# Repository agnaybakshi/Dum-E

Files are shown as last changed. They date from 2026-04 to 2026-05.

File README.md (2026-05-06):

# Vision Arm Teleoperation v1

This project is a first working teleoperation stack for a small 5-servo tabletop arm driven by a single front-facing webcam, Python, and a PCA9685-based controller board. The laptop-side teleop logic now treats the base as a bounded positional yaw joint, and the transport can be either Arduino serial or ESP32 Wi-Fi UDP.

## Architecture summary

- `main.py` runs the control loop, keyboard safety controls, target generation, and transport output.
- `vision.py` tracks one hand with MediaPipe Hands and extracts stable hand features.
- `hand_mapping.py` converts hand motion into teleop controls:
  - horizontal hand offset -> joystick-style bounded base yaw motion
  - vertical hand position -> upper-arm pitch target
  - relative hand size/depth proxy -> lower-arm pitch target
  - upper/lower average -> middle-arm pitch target
  - whole-hand finger curl -> gripper opening
- `filters.py` provides low-pass filters, deadbands, and slew limiting.
- `transport.py` defines the shared teleop packet and transport interface.
- `serial_comm.py` is the serial transport implementation.
- `udp_comm.py` is the UDP transport implementation.
- `send.py` is a UDP diagnostic sender for quick ESP32 firmware testing.
- `calibration.py` loads/saves JSON calibration and exports generated firmware headers.
- `arduino/vision_arm_uno.ino` parses packets, clamps values, applies watchdogs, and drives the servos through the PCA9685.
- `arduino/esp32/vision_arm_esp` is the ESP32 DevKit V1 PlatformIO target using Arduino framework, Wi-Fi UDP, and PCA9685.

## Important design limits

- The base is now treated as a bounded positional yaw joint with about `180` degrees of travel.
- The firmware still receives a bounded target yaw angle, but the host now drives that angle with joystick-style left/right rate control so the hand can return to center to stop.
- The single RGB camera provides only a relative depth proxy. Reach control is therefore relative and must be tuned experimentally.
- The current teleop version uses direct joint mapping for the three pitch joints:
  - lower joint from relative depth
  - upper joint from hand height
  - middle joint as the average of upper and lower

## Files

- `config/calibration.json`: primary tuning and calibration source
- `arduino/generated_calibration.h`: generated from the JSON for the Uno sketch
- `arduino/vision_arm_uno.ino`: flash this to the Arduino Uno
- `arduino/esp32/vision_arm_esp`: PlatformIO project for ESP32 DevKit V1

## Python setup

1. Create and activate a Python environment.
   Note: python v3.11 and mediapipe version v0.10.14 is required to run this project successfully. It is recommended to have these and the dependencies in a virtual enviorment
3. Install dependencies:

```bash
pip install -r requirements.txt
```

3. Edit `config/calibration.json` and select a transport:
   - serial: set `transport.kind` to `serial` and choose `serial.port`
   - UDP: set `transport.kind` to `udp` and use the fixed ESP32 IP from `wifi_secrets.h` for `udp.host` (default in this repo: `192.168.137.50`), then keep `udp.port: 4210`
4. Regenerate the firmware headers:

```bash
python calibration.py export-firmware
```

5. Flash either:
   - `arduino/vision_arm_uno.ino` for the Uno serial path
   - `arduino/esp32/vision_arm_esp` for the ESP32 UDP path
6. Run the teleop app:

```bash
python main.py
```

Optional dry-run without transport:

```bash
python main.py --no-serial
```

Install the Arduino library `Adafruit PWM Servo Driver Library` before building either firmware target.

PCA9685 wiring and channel map for Arduino Uno:
- I2C SDA -> `A4`
- I2C SCL -> `A5`
- Base yaw servo -> channel `0`
- Lower arm pitch -> channel `1`
- Middle arm pitch -> channel `2`
- Upper arm pitch -> channel `3`
- Gripper -> channel `4`

## Keyboard controls

- `q`: quit
- `f` or `space`: freeze/unfreeze teleop
- `x`: toggle emergency stop
- `h`: send home/hold request
- `n`: capture current hand as neutral position and depth reference
- `[`: slow the base yaw rate down
- `]`: speed the base yaw rate up

## ESP32 UDP migration

What changed:

- The laptop still generates the same teleop command semantics and the same packet format:

```text
T,seq,mode,base_deg,lower_deg,middle_deg,upper_deg,gripper_open
```

- `main.py` now selects either serial or UDP transport from config.
- The ESP32 firmware receives those exact ASCII packets over UDP and drives the PCA9685 with the same calibration mapping style as the Uno firmware.

Wi-Fi setup:

1. Copy [wifi_secrets.h.example](C:/Users/agnay/Documents/Agnisys/vision_arm/arduino/esp32/vision_arm_esp/include/wifi_secrets.h.example) to `wifi_secrets.h`.
2. Edit [wifi_secrets.h](C:/Users/agnay/Documents/Agnisys/vision_arm/arduino/esp32/vision_arm_esp/include/wifi_secrets.h).
3. Set `VISION_ARM_WIFI_SSID` and `VISION_ARM_WIFI_PASSWORD`.
4. `wifi_secrets.h` is intentionally ignored by Git and should not be committed.
5. Set the static IP values in the same file. This repo currently uses:
   - `VISION_ARM_WIFI_STATIC_IP = 192.168.137.50`
   - `VISION_ARM_WIFI_GATEWAY = 192.168.137.1`
   - `VISION_ARM_WIFI_SUBNET = 255.255.255.0`
6. Make sure that SSID is a `2.4 GHz` network. ESP32 DevKit V1 does not join `5 GHz` Wi-Fi.
7. If you move to a different Wi-Fi subnet later, update both `wifi_secrets.h` and `udp.host` in `config/calibration.json` to match that subnet.

ESP32 wiring to the PCA9685:

- `GPIO21` -> PCA9685 `SDA`
- `GPIO22` -> PCA9685 `SCL`
- `3V3` -> PCA9685 `VCC`
- `GND` -> PCA9685 `GND`
- external servo supply `+` -> PCA9685 `V+`
- external servo supply `-` -> PCA9685 `GND`

The ESP32 ground, PCA9685 ground, and servo power ground must all be common.

Flash the ESP32 with PlatformIO:

```bash
cd arduino/esp32/vision_arm_esp
pio run
pio run --target upload
pio device monitor
```

The ESP32 will request the fixed IP from `wifi_secrets.h` and print that IP plus the UDP listen port after it successfully joins Wi-Fi.

Test the ESP32 without MediaPipe:

```bash
python send.py --host 192.168.137.50 --port 4210 --mode A --base 90 --lower 10 --middle 20 --upper 30 --gripper 0.5 --rate 20 --count 0
```

Switch transports in `config/calibration.json`:

- serial:

```json
"transport": { "kind": "serial", "enabled": true }
```

- udp:

```json
"transport": { "kind": "udp", "enabled": true }
```

What remains unchanged:

- camera / MediaPipe hand tracking
- pitch-joint filtering and mapping logic
- teleop modes `A`, `H`, `S`, `M`
- joint-angle and gripper-open command semantics for lower/middle/upper/gripper
- calibration JSON as the master source

## Calibration workflow

Use the JSON as the master calibration file, then regenerate the firmware headers whenever firmware constants change.

### Vision and teleop

1. Start with `python main.py --no-serial`.
2. Stand in front of the camera with your operating hand in the intended neutral position.
3. Press `n` to store `neutral_x`, `neutral_y`, and `depth_reference`.
4. If needed, set grip references from the command line with `python calibration.py set-grip --open ... --closed ...`.
5. Tune `mapping.yaw_deadband`, `mapping.yaw_exponent`, `mapping.yaw_max_rate_deg_s`, `filters.yaw_rate_alpha`, and `filters.yaw_stop_rate_deg_s` until yaw feels natural.

### Servo and base calibration

1. Power the arm safely with the links unloaded or mechanically free to move.
2. Keep `freeze_on_start` set to `true` until calibration is complete.
3. Edit the firmware section in `config/calibration.json`:
   - `base_center_deg`
   - `base_home_deg`
   - `base_min_deg`
   - `base_max_deg`
   - `lower_zero_deg`, `middle_zero_deg`, `upper_zero_deg`
   - `lower_sign`, `middle_sign`, `upper_sign`
   - `gripper_open_servo_deg`, `gripper_closed_servo_deg`
4. Run:

```bash
python calibration.py export-firmware
```

5. Rebuild and reflash the target firmware after header changes.

### Base yaw calibration

For the direct-drive positional base:

1. Verify that `base_min_deg` and `base_max_deg` match the safe mechanical travel of the new yaw joint.
2. Set `base_center_deg` so a centered hand points the arm straight ahead.
3. Set `base_home_deg` to the startup/home angle you want the arm to return to.
4. Use the `[` and `]` keys to change `mapping.yaw_max_rate_deg_s` live while the app is running.
5. If you need to change the physical center angle, edit `base_center_deg` or use `python calibration.py set-base-center --deg ...`.
6. After you settle on the new center or limits, run:

```bash
python calibration.py export-firmware
```

7. Rebuild and reflash the target firmware so startup, watchdog hold, and home use the same base constants.

## Teleop protocol

Python sends newline-terminated packets:

```text
T,seq,mode,base_deg,lower_deg,middle_deg,upper_deg,gripper_open
```

- `mode`:
  - `A` active teleop
  - `H` hold the last pose, including the current base angle
  - `S` emergency stop hold at the current pose
  - `M` go to configured home pose
- `base_deg`: bounded base yaw target angle in degrees
- `lower_deg`, `middle_deg`, `upper_deg`: pitch joint output angles in degrees
- `gripper_open`: normalized gripper openness in `[0, 1]`

## Safety notes

- The arm does not move unless the hand is confidently tracked and teleop is unfrozen.
- Tracking loss holds the last commanded base angle and pitch pose.
- The firmware watchdog holds the last commanded base angle if packets stop arriving.
- Startup can perform a short hello wave on the upper pitch joint after homing.
- Both Python and the active firmware target clamp commands before motion.
- Start with conservative base travel limits until the new yaw mechanism is tuned.
- The PCA9685 servo rail still needs external servo power and a common ground with the Arduino.

## Future upgrades

- Add base encoder feedback and upgrade to full 3D Cartesian IK.
- Add table calibration and workspace visualization in robot coordinates.
- Add logging and replay for tuning hand mappings.
- Add an overhead camera or multi-camera fusion for better depth and pick/place precision.
- Add optional assisted grasp modes after manual teleop is stable.

If you accidentally staged `wifi_secrets.h`, remove it before committing:

```bash
git rm --cached arduino/esp32/vision_arm_esp/include/wifi_secrets.h
```

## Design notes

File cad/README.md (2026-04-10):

# CAD Details
Most of the structure is credited to SG90 mini robot arm S9 by FrN (Robot Arm for everyone!)
by Francis128 is licensed under the Creative Commons - Attribution - Non-Commercial license.

The custom base is designed to replace the native geared base yaw joint for a direct servo driven yaw. 

The project requires three MG90s and two SG90 servos where the MG90s are used for the base yaw, lower pitch and middle pitch joints while the SG90 are used for the upper pitch joint and the gripper end effector. 

PLA and ABS are advised for structural components and gears respectively.

4mm steel balls are used in the base to make the yaw motion smoother.

M2 & M2.5 screws and heat inserts are used through out to uphold the structure.

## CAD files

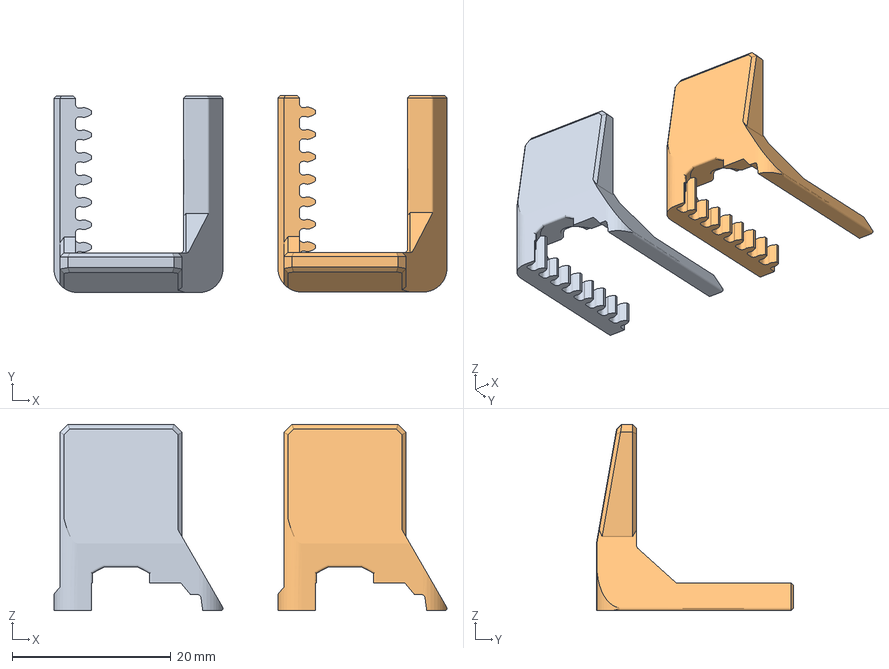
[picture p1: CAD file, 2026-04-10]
cad/clamp_main.3mf
49.5 x 24.9 x 23.5 mm
clamp_jaw_2_pcs.STL x 2

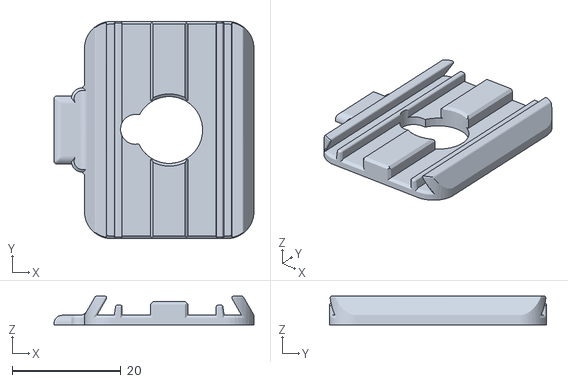
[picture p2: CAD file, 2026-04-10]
cad/clamp_main_A.stl
36.8 x 40.0 x 5.26

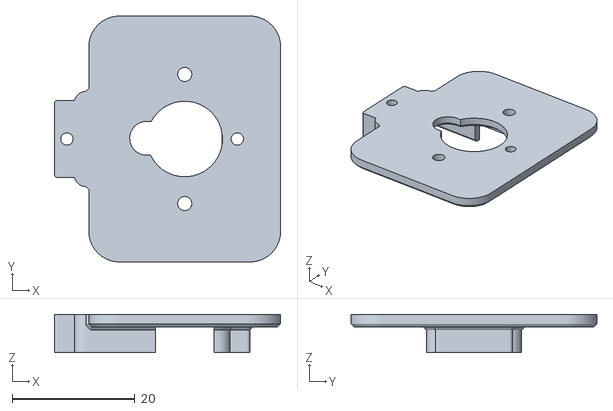
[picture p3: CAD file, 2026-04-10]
cad/clamp_main_B.stl
36.8 x 40.0 x 6.24

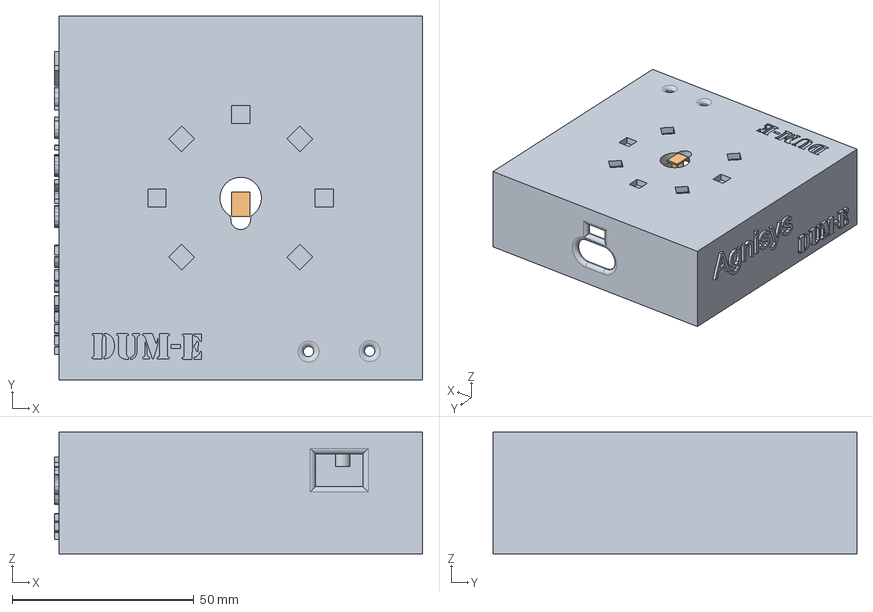
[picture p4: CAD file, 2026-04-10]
cad/basev2 p1m5.step
101.2 x 100.0 x 33.5 mm

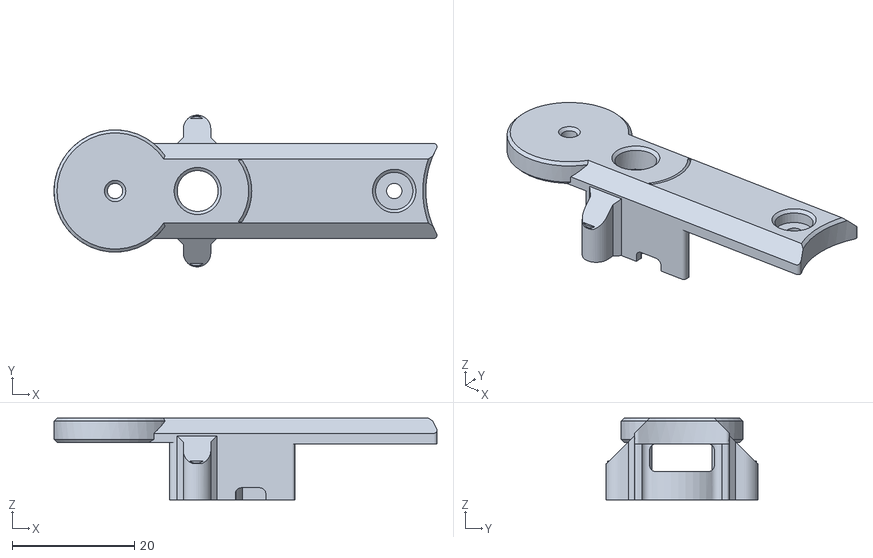
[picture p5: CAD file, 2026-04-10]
cad/Arm-S_hsg2_mod.stl
62.6 x 24.8 x 13.4

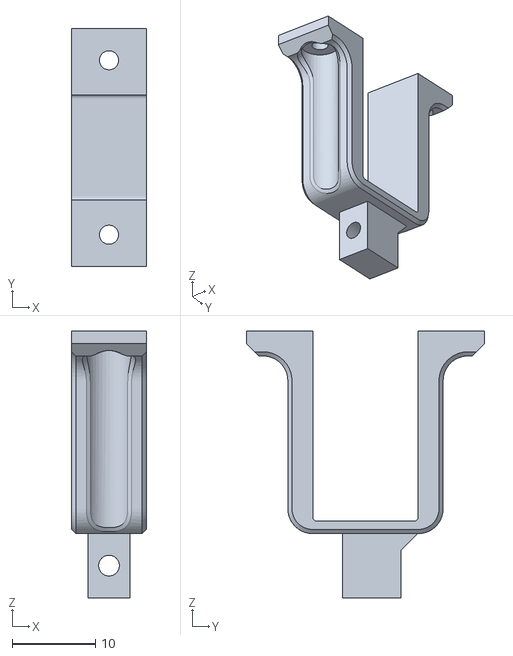
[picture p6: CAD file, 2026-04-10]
cad/clamp_yMount.STL
9.00 x 28.7 x 32.1

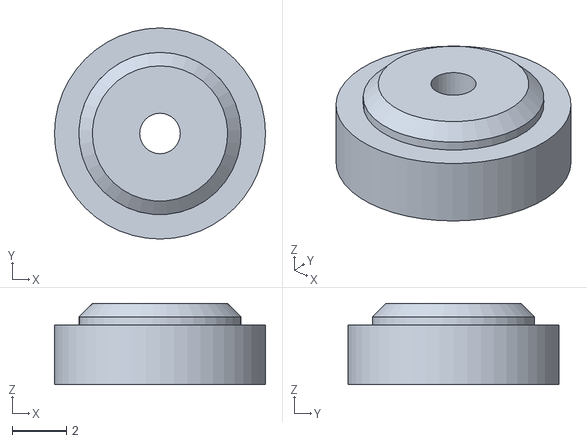
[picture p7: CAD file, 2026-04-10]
cad/lowerBearing.stl
7.80 x 7.80 x 3.00

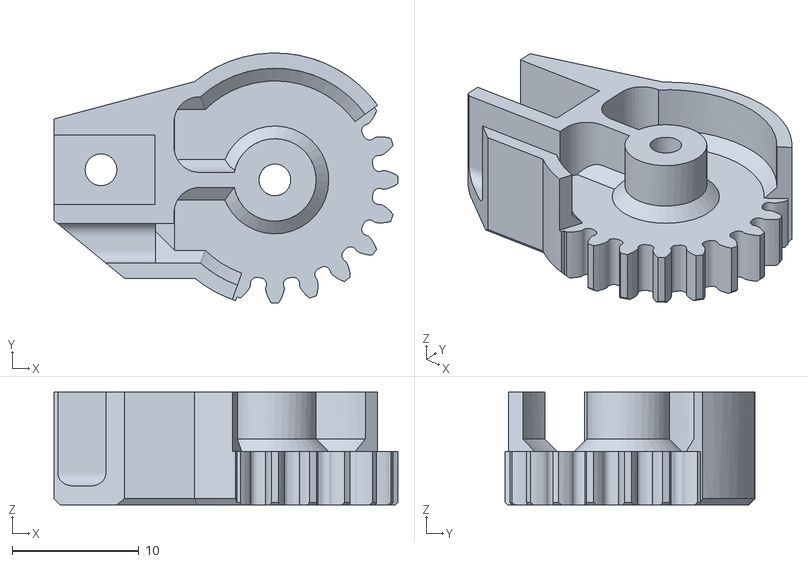
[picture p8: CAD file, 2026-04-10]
cad/Arm-S_middle.STL
27.1 x 19.7 x 8.90

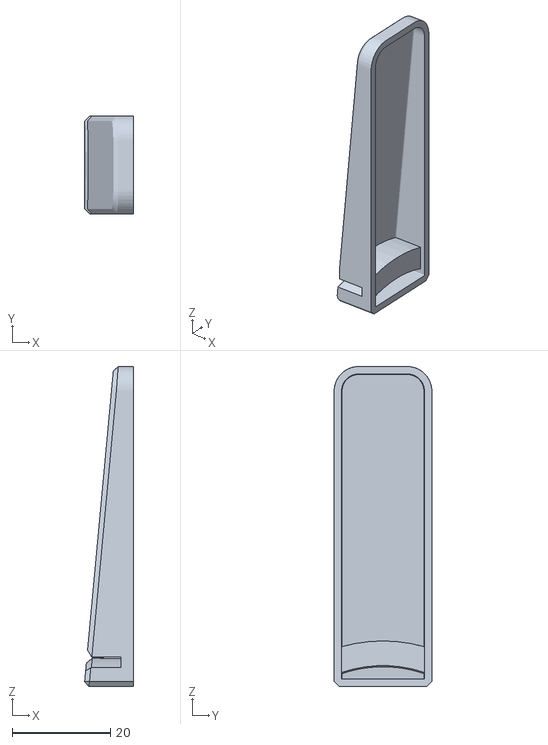
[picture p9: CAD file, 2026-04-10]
cad/Arm-L_leg_3_pcs.STL
9.91 x 19.9 x 65.0

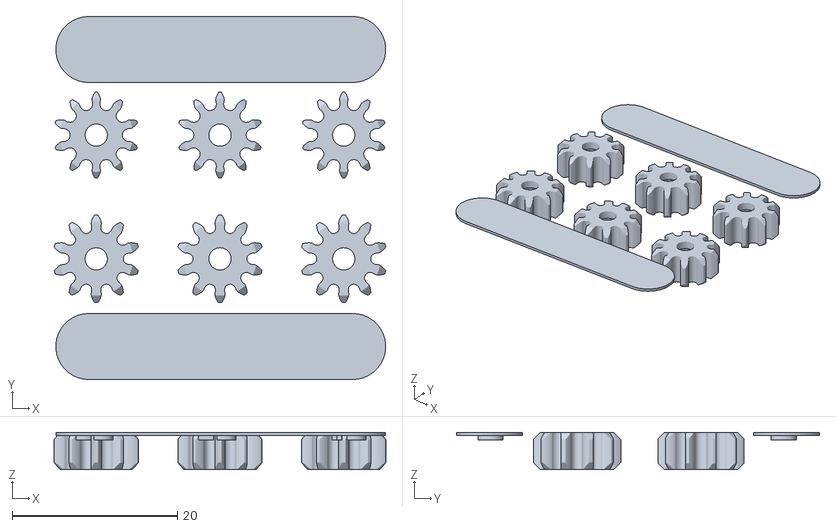
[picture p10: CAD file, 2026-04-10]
cad/gear1s_5_pcs.STL
40.2 x 44.0 x 4.50

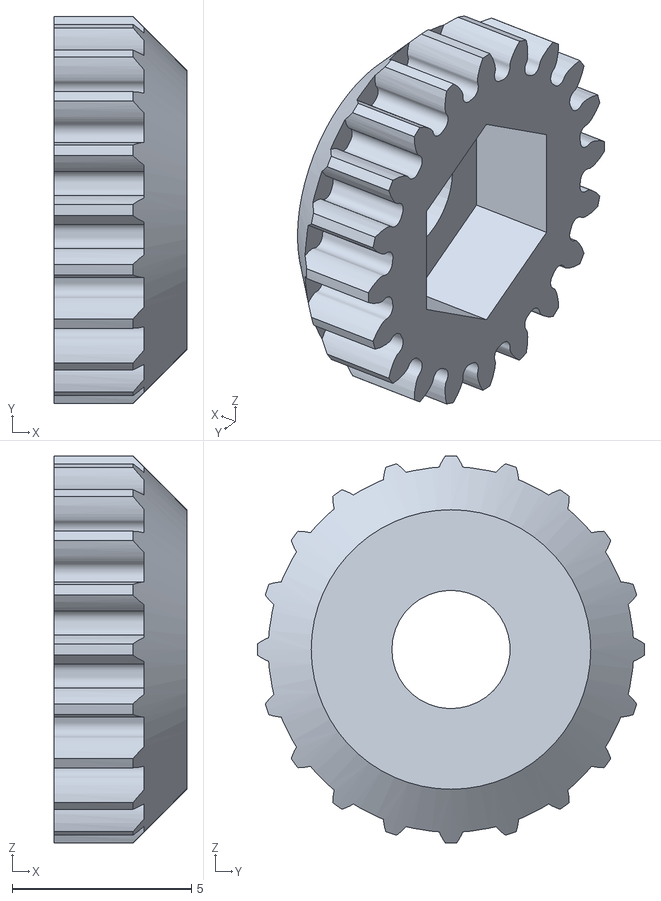
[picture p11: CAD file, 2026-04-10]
cad/Arm-L_nutKnob.STL
3.70 x 10.8 x 10.8

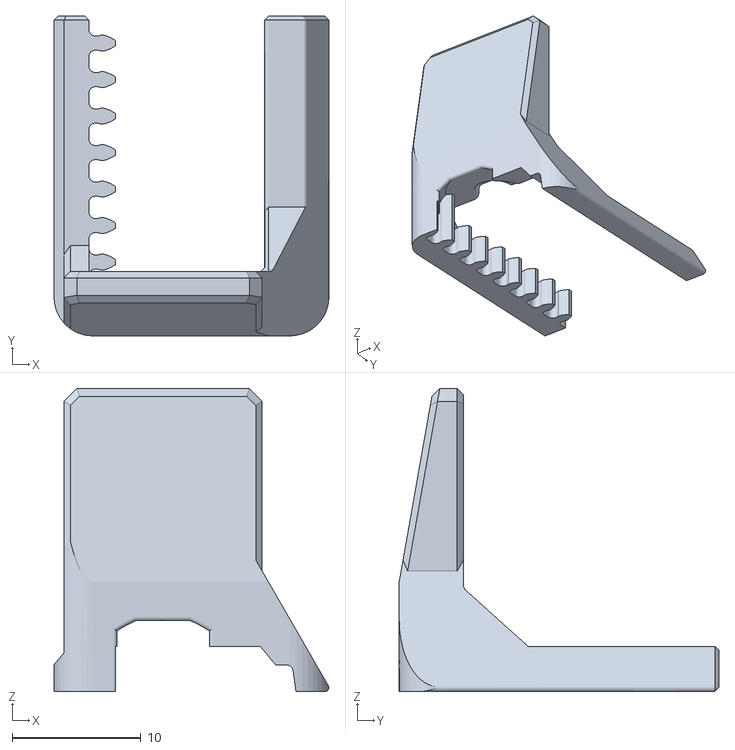
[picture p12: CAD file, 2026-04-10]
cad/clamp_jaw_2_pcs.STL
21.3 x 24.8 x 23.5

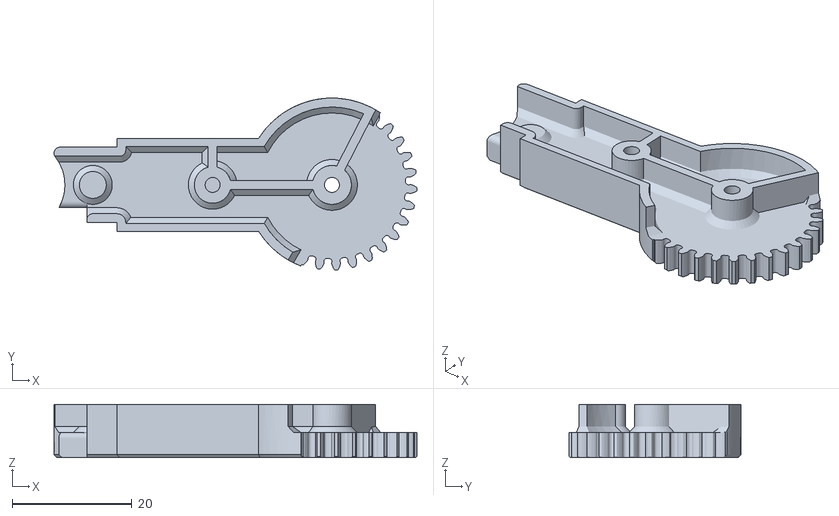
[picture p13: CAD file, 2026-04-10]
cad/Arm-M_middle.STL
60.6 x 28.7 x 8.90

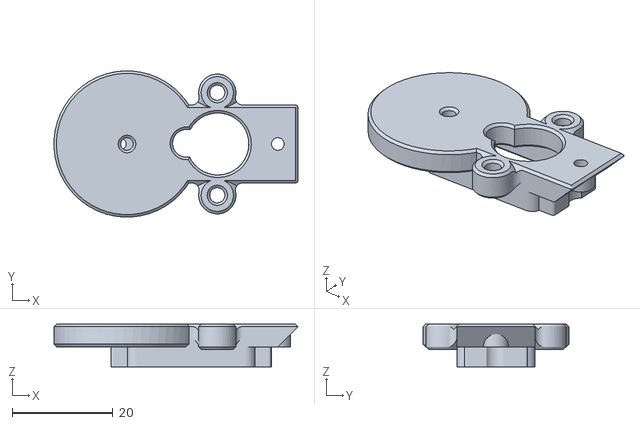
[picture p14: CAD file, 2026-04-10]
cad/Arm-M_hsg1.STL
48.4 x 29.0 x 8.50

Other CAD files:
cad/Arm-S_hsg2.STL
cad/Arm-L_VRmount_mod.stl
cad/Arm-L_middle.STL
cad/Arm-S_hsg1.STL
cad/Arm-L_hsg2.3mf
cad/Arm-L_hsg2.STL
cad/Arm-M_hsg2.STL
cad/clamp_main.STL

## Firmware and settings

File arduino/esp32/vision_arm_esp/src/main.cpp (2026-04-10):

#include <Arduino.h>
#include <WiFi.h>
#include <WiFiUdp.h>
#include <Wire.h>
#include <Adafruit_PWMServoDriver.h>
#include <math.h>
#include <stdlib.h>
#include <string.h>

#include "generated_calibration.h"
#include "wifi_secrets.h"

constexpr uint8_t BASE_CHANNEL = 0;
constexpr uint8_t LOWER_CHANNEL = 1;
constexpr uint8_t MIDDLE_CHANNEL = 2;
constexpr uint8_t UPPER_CHANNEL = 3;
constexpr uint8_t GRIPPER_CHANNEL = 4;

constexpr uint8_t PCA9685_DEVICE_ADDRESS = 0x40;
constexpr float PCA9685_SERVO_FREQ_HZ = 50.0f;
constexpr float SERVO_MIN_PULSE_US = 500.0f;
constexpr float SERVO_MAX_PULSE_US = 2500.0f;
constexpr uint16_t UDP_LISTEN_PORT = 4210;
constexpr unsigned long WIFI_RETRY_INTERVAL_MS = 5000UL;
constexpr unsigned long WIFI_CONNECT_TIMEOUT_MS = 15000UL;
constexpr float BASE_WRITE_EPSILON_DEG = 0.5f;

constexpr float LOWER_JOINT_MIN_DEG = 0.0f;
constexpr float LOWER_JOINT_MAX_DEG = 45.0f;
constexpr float MIDDLE_JOINT_MIN_DEG = 0.0f;
constexpr float MIDDLE_JOINT_MAX_DEG = 60.0f;
constexpr float UPPER_JOINT_MIN_DEG = 0.0f;
constexpr float UPPER_JOINT_MAX_DEG = 90.0f;
constexpr size_t RX_BUFFER_SIZE = 128;

struct CommandTarget {
  char mode = 'H';
  float baseDeg = BASE_HOME_DEG;
  float lowerJointDeg = 0.0f;
  float middleJointDeg = 0.0f;
  float upperJointDeg = 0.0f;
  float gripperOpen = STARTUP_GRIPPER_OPEN_FRACTION;
  unsigned long sequence = 0UL;
};

Adafruit_PWMServoDriver pwm = Adafruit_PWMServoDriver(PCA9685_DEVICE_ADDRESS);
WiFiUDP udp;

CommandTarget target;
float currentBaseDeg = BASE_HOME_DEG;
float currentLowerServoDeg = LOWER_SERVO_ZERO_DEG;
float currentMiddleServoDeg = MIDDLE_SERVO_ZERO_DEG;
float currentUpperServoDeg = UPPER_SERVO_ZERO_DEG;
float currentGripperServoDeg =
    GRIPPER_CLOSED_SERVO_DEG + STARTUP_GRIPPER_OPEN_FRACTION * (GRIPPER_OPEN_SERVO_DEG - GRIPPER_CLOSED_SERVO_DEG);
float lastWrittenBaseServoDeg = BASE_HOME_DEG;

char rxBuffer[RX_BUFFER_SIZE];
unsigned long lastPacketMs = 0UL;
unsigned long lastUpdateMs = 0UL;
unsigned long lastWifiAttemptMs = 0UL;
char lastLoggedMode = '\0';
bool udpStarted = false;
wl_status_t lastWifiStatus = WL_IDLE_STATUS;

float clampf(float value, float lower, float upper) {
  if (value < lower) {
    return lower;
  }
  if (value > upper) {
    return upper;
  }
  return value;
}

float slewToward(float current, float targetValue, float maxDelta) {
  float delta = targetValue - current;
  if (delta > maxDelta) {
    delta = maxDelta;
  } else if (delta < -maxDelta) {
    delta = -maxDelta;
  }
  return current + delta;
}

float lowerJointToServo(float jointDeg) {
  float servoDeg = LOWER_SERVO_ZERO_DEG + LOWER_SERVO_SIGN * LOWER_GEAR_RATIO * jointDeg;
  return clampf(servoDeg, LOWER_SERVO_MIN_DEG, LOWER_SERVO_MAX_DEG);
}

float middleJointToServo(float jointDeg) {
  float servoDeg = MIDDLE_SERVO_ZERO_DEG + MIDDLE_SERVO_SIGN * MIDDLE_GEAR_RATIO * jointDeg;
  return clampf(servoDeg, MIDDLE_SERVO_MIN_DEG, MIDDLE_SERVO_MAX_DEG);
}

float upperJointToServo(float jointDeg) {
  float servoDeg = UPPER_SERVO_ZERO_DEG + UPPER_SERVO_SIGN * UPPER_GEAR_RATIO * jointDeg;
  return clampf(servoDeg, UPPER_SERVO_MIN_DEG, UPPER_SERVO_MAX_DEG);
}

float gripperOpenToServo(float openFraction) {
  float openClamped = clampf(openFraction, 0.0f, 1.0f);
  float servoDeg = GRIPPER_CLOSED_SERVO_DEG + openClamped * (GRIPPER_OPEN_SERVO_DEG - GRIPPER_CLOSED_SERVO_DEG);
  int lower = min(GRIPPER_CLOSED_SERVO_DEG, GRIPPER_OPEN_SERVO_DEG);
  int upper = max(GRIPPER_CLOSED_SERVO_DEG, GRIPPER_OPEN_SERVO_DEG);
  return clampf(servoDeg, lower, upper);
}

float baseJointToServo(float baseDeg) {
  return clampf(baseDeg, BASE_MIN_DEG, BASE_MAX_DEG);
}

uint16_t servoDegToTicks(float servoDeg) {
  float degClamped = clampf(servoDeg, 0.0f, 180.0f);
  float pulseUs = SERVO_MIN_PULSE_US + (degClamped / 180.0f) * (SERVO_MAX_PULSE_US - SERVO_MIN_PULSE_US);
  float ticks = (pulseUs * PCA9685_SERVO_FREQ_HZ * 4096.0f) / 1000000.0f;
  return static_cast<uint16_t>(clampf(ticks, 0.0f, 4095.0f));
}

void writeServoChannel(uint8_t channel, float servoDeg) {
  pwm.setPWM(channel, 0, servoDegToTicks(servoDeg));
}

void holdPose() {
  target.mode = 'H';
}

void goHome() {
  target.mode = 'M';
  target.baseDeg = BASE_HOME_DEG;
  target.lowerJointDeg = 0.0f;
  target.middleJointDeg = 0.0f;
  target.upperJointDeg = 0.0f;
  target.gripperOpen = STARTUP_GRIPPER_OPEN_FRACTION;
}

bool parseFloatField(const char *text, float &value) {
  char *endPtr = nullptr;
  value = static_cast<float>(strtod(text, &endPtr));
  return endPtr != text && *endPtr == '\0';
}

bool parseUnsignedField(const char *text, unsigned long &value) {
  char *endPtr = nullptr;
  value = strtoul(text, &endPtr, 10);
  return endPtr != text && *endPtr == '\0';
}

bool parsePacket(char *line) {
  char *tokens[8];
  uint8_t count = 0;
  char *context = nullptr;
  char *token = strtok_r(line, ",", &context);
  while (token != nullptr && count < 8) {
    tokens[count++] = token;
    token = strtok_r(nullptr, ",", &context);
  }
  if (count != 8 || strcmp(tokens[0], "T") != 0) {
    return false;
  }

  unsigned long sequence = 0UL;
  float baseDeg = 0.0f;
  float lowerJoint = 0.0f;
  float middleJoint = 0.0f;
  float upperJoint = 0.0f;
  float gripperOpen = 0.0f;
  if (!parseUnsignedField(tokens[1], sequence)) {
    return false;
  }

  char mode = tokens[2][0];
  if (tokens[2][1] != '\0' || (mode != 'A' && mode != 'H' && mode != 'S' && mode != 'M')) {
    return false;
  }

  if (!parseFloatField(tokens[3], baseDeg) || !parseFloatField(tokens[4], lowerJoint) ||
      !parseFloatField(tokens[5], middleJoint) || !parseFloatField(tokens[6], upperJoint) ||
      !parseFloatField(tokens[7], gripperOpen)) {
    return false;
  }

  target.sequence = sequence;
  if (mode == 'M') {
    goHome();
  } else if (mode == 'A') {
    target.mode = mode;
    target.baseDeg = clampf(baseDeg, BASE_MIN_DEG, BASE_MAX_DEG);
    target.lowerJointDeg = clampf(lowerJoint, LOWER_JOINT_MIN_DEG, LOWER_JOINT_MAX_DEG);
    target.middleJointDeg = clampf(middleJoint, MIDDLE_JOINT_MIN_DEG, MIDDLE_JOINT_MAX_DEG);
    target.upperJointDeg = clampf(upperJoint, UPPER_JOINT_MIN_DEG, UPPER_JOINT_MAX_DEG);
    target.gripperOpen = clampf(gripperOpen, 0.0f, 1.0f);
  } else {
    target.mode = mode;
  }
  return true;
}

void logModeTransition() {
  if (target.mode != lastLoggedMode) {
    Serial.printf("Mode -> %c (seq=%lu)\n", target.mode, target.sequence);
    lastLoggedMode = target.mode;
  }
}

void beginUdpIfNeeded() {
  if (!udpStarted && WiFi.status() == WL_CONNECTED) {
    udp.begin(UDP_LISTEN_PORT);
    udpStarted = true;
    Serial.printf("UDP listening on port %u\n", UDP_LISTEN_PORT);
  }
}

void connectWifi() {
  if (WiFi.status() == WL_CONNECTED) {
    return;
  }

  Serial.printf("Connecting to Wi-Fi SSID '%s'\n", VISION_ARM_WIFI_SSID);
  WiFi.mode(WIFI_STA);
  WiFi.persistent(false);
  WiFi.setSleep(false);
  WiFi.setAutoReconnect(true);
  if (!WiFi.config(
          VISION_ARM_WIFI_STATIC_IP,
          VISION_ARM_WIFI_GATEWAY,
          VISION_ARM_WIFI_SUBNET,
          VISION_ARM_WIFI_DNS1,
          VISION_ARM_WIFI_DNS2)) {
    Serial.println("Warning: failed to apply static IP config.");
  }
  WiFi.begin(VISION_ARM_WIFI_SSID, VISION_ARM_WIFI_PASSWORD);

  unsigned long startMs = millis();
  while (WiFi.status() != WL_CONNECTED && (millis() - startMs) < WIFI_CONNECT_TIMEOUT_MS) {
    delay(250);
    Serial.print(".");
  }
  Serial.println();

  if (WiFi.status() == WL_CONNECTED) {
    Serial.printf("Wi-Fi connected, IP=%s\n", WiFi.localIP().toString().c_str());
    lastWifiStatus = WL_CONNECTED;
    beginUdpIfNeeded();
  } else {
    Serial.printf("Wi-Fi connect timed out; status=%d. Will retry in loop.\n", static_cast<int>(WiFi.status()));
    lastWifiStatus = WiFi.status();
  }
}

void maintainWifi() {
  wl_status_t wifiStatus = WiFi.status();
  if (wifiStatus == WL_CONNECTED) {
    if (lastWifiStatus != WL_CONNECTED) {
      Serial.printf("Wi-Fi connected, IP=%s\n", WiFi.localIP().toString().c_str());
    }
    lastWifiStatus = WL_CONNECTED;
    beginUdpIfNeeded();
    return;
  }

  if (udpStarted) {
    udp.stop();
    udpStarted = false;
  }
  if (lastWifiStatus == WL_CONNECTED) {
    Serial.println("Wi-Fi disconnected.");
  }
  lastWifiStatus = wifiStatus;
  unsigned long nowMs = millis();
  if (nowMs - lastWifiAttemptMs >= WIFI_RETRY_INTERVAL_MS) {
    lastWifiAttemptMs = nowMs;
    Serial.printf("Wi-Fi disconnected (status=%d), retrying...\n", static_cast<int>(wifiStatus));
    WiFi.disconnect();
    WiFi.begin(VISION_ARM_WIFI_SSID, VISION_ARM_WIFI_PASSWORD);
  }
}

void processUdp() {
  if (!udpStarted) {
    return;
  }

  int packetSize = udp.parsePacket();
  if (packetSize <= 0) {
    return;
  }

  int readLength = udp.read(rxBuffer, RX_BUFFER_SIZE - 1);
  if (readLength <= 0) {
    return;
  }
  rxBuffer[readLength] = '\0';

  while (readLength > 0 && (rxBuffer[readLength - 1] == '\n' || rxBuffer[readLength - 1] == '\r')) {
    rxBuffer[--readLength] = '\0';
  }

  if (readLength > 0 && parsePacket(rxBuffer)) {
    lastPacketMs = millis();
    logModeTransition();
    udp.beginPacket(udp.remoteIP(), udp.remotePort());
    udp.printf("OK,%lu,%c\n", target.sequence, target.mode);
    udp.endPacket();
  } else {
    Serial.printf("Malformed UDP packet from %s:%u\n", udp.remoteIP().toString().c_str(), udp.remotePort());
    udp.beginPacket(udp.remoteIP(), udp.remotePort());
    udp.print("ERR\n");
    udp.endPacket();
  }
}

void updateOutputs() {
  unsigned long nowMs = millis();
  float dt = (nowMs - lastUpdateMs) * 0.001f;
  lastUpdateMs = nowMs;
  if (dt <= 0.0f) {
    dt = 0.02f;
  }

  if (nowMs - lastPacketMs > WATCHDOG_TIMEOUT_MS) {
    if (target.mode != 'H') {
      Serial.println("Watchdog timeout, entering hold.");
    }
    holdPose();
  }

  float targetBaseDeg = clampf(target.baseDeg, BASE_MIN_DEG, BASE_MAX_DEG);
  float lowerServoTarget = lowerJointToServo(target.lowerJointDeg);
  float middleServoTarget = middleJointToServo(target.middleJointDeg);
  float upperServoTarget = upperJointToServo(target.upperJointDeg);
  float gripperServoTarget = gripperOpenToServo(target.gripperOpen);

  currentBaseDeg = slewToward(currentBaseDeg, targetBaseDeg, BASE_SLEW_DEG_PER_S * dt);
  currentLowerServoDeg = slewToward(currentLowerServoDeg, lowerServoTarget, SERVO_SLEW_DEG_PER_S * dt);
  currentMiddleServoDeg = slewToward(currentMiddleServoDeg, middleServoTarget, SERVO_SLEW_DEG_PER_S * dt);
  currentUpperServoDeg = slewToward(currentUpperServoDeg, upperServoTarget, SERVO_SLEW_DEG_PER_S * dt);
  currentGripperServoDeg = slewToward(currentGripperServoDeg, gripperServoTarget, SERVO_SLEW_DEG_PER_S * dt);

  float baseServoDeg = baseJointToServo(currentBaseDeg);
  if (fabsf(baseServoDeg - lastWrittenBaseServoDeg) >= BASE_WRITE_EPSILON_DEG) {
    writeServoChannel(BASE_CHANNEL, baseServoDeg);
    lastWrittenBaseServoDeg = baseServoDeg;
  }
  writeServoChannel(LOWER_CHANNEL, currentLowerServoDeg);
  writeServoChannel(MIDDLE_CHANNEL, currentMiddleServoDeg);
  writeServoChannel(UPPER_CHANNEL, currentUpperServoDeg);
  writeServoChannel(GRIPPER_CHANNEL, currentGripperServoDeg);
}

void setup() {
  Serial.begin(115200);
  delay(100);

  Wire.begin();
  pwm.begin();
  pwm.setPWMFreq(PCA9685_SERVO_FREQ_HZ);
  delay(10);

  goHome();
  lastPacketMs = millis();
  lastUpdateMs = millis();
  lastWifiAttemptMs = millis();

  writeServoChannel(BASE_CHANNEL, baseJointToServo(BASE_HOME_DEG));
  lastWrittenBaseServoDeg = baseJointToServo(BASE_HOME_DEG);
  writeServoChannel(LOWER_CHANNEL, currentLowerServoDeg);
  writeServoChannel(MIDDLE_CHANNEL, currentMiddleServoDeg);
  writeServoChannel(UPPER_CHANNEL, currentUpperServoDeg);
  writeServoChannel(GRIPPER_CHANNEL, currentGripperServoDeg);

  connectWifi();
}

void loop() {
  maintainWifi();
  processUdp();
  updateOutputs();
  delay(5);
}

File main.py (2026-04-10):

from __future__ import annotations

import argparse
import sys
import time
from dataclasses import dataclass

import cv2

from calibration import (
    capture_neutral_reference,
    export_firmware_headers,
)
from config import AppConfig, load_config, save_config
from filters import LowPassFilter, SlewRateLimiter, clamp
from hand_mapping import compute_base_velocity_deg_per_s, compute_joint_norms, extract_signals
from transport import TeleopCommand, build_transport
from ui_overlay import draw_overlay
from vision import HandTracker


@dataclass
class JointState:
    lower_deg: float = 0.0
    middle_deg: float = 0.0
    upper_deg: float = 0.0


def _parse_args() -> argparse.Namespace:
    parser = argparse.ArgumentParser(description="Single-camera hand teleop for a 5-servo robotic arm.")
    parser.add_argument("--config", default="config/calibration.json", help="Calibration JSON path.")
    parser.add_argument("--transport", choices=("serial", "udp"), help="Override transport kind.")
    parser.add_argument("--serial-port", help="Override serial port from config.")
    parser.add_argument("--udp-host", help="Override UDP target host from config.")
    parser.add_argument("--udp-port", type=int, help="Override UDP target port from config.")
    parser.add_argument("--camera", type=int, help="Override camera device index.")
    parser.add_argument("--no-serial", action="store_true", help="Run without sending commands.")
    parser.add_argument(
        "--export-arduino-header",
        action="store_true",
        help="Refresh generated firmware headers before starting.",
    )
    return parser.parse_args()


def _open_camera(config: AppConfig) -> cv2.VideoCapture:
    cap = cv2.VideoCapture(config.camera.device_index, cv2.CAP_DSHOW)
    cap.set(cv2.CAP_PROP_FRAME_WIDTH, config.camera.frame_width)
    cap.set(cv2.CAP_PROP_FRAME_HEIGHT, config.camera.frame_height)
    cap.set(cv2.CAP_PROP_FPS, config.camera.fps)
    cap.set(cv2.CAP_PROP_BUFFERSIZE, 1)
    if not cap.isOpened():
        raise RuntimeError(f"Could not open camera index {config.camera.device_index}.")
    return cap


def _build_filters(config: AppConfig) -> dict[str, object]:
    return {
        "x": LowPassFilter(config.filters.x_alpha),
        "height": LowPassFilter(config.filters.y_alpha),
        "depth": LowPassFilter(config.filters.depth_alpha),
        "grip": LowPassFilter(config.filters.grip_alpha),
        "yaw_rate": LowPassFilter(config.filters.yaw_rate_alpha, 0.0),
        "base": SlewRateLimiter(config.firmware.base_slew_deg_s, float(config.firmware.base_home_deg)),
        "lower": SlewRateLimiter(config.filters.joint_rate_deg_s, 0.0),
        "middle": SlewRateLimiter(config.filters.joint_rate_deg_s, 0.0),
        "upper": SlewRateLimiter(config.filters.joint_rate_deg_s, 0.0),
        "gripper": SlewRateLimiter(
            config.filters.gripper_rate_per_s,
            config.firmware.startup_gripper_open_fraction,
        ),
    }

def _home_joints() -> JointState:
    return JointState()


def _apply_runtime_overrides(config: AppConfig, args: argparse.Namespace) -> None:
    if args.transport:
        config.transport.kind = args.transport
    if args.serial_port:
        config.serial.port = args.serial_port
    if args.udp_host:
        config.udp.host = args.udp_host
    if args.udp_port is not None:
        config.udp.port = args.udp_port
    if args.camera is not None:
        config.camera.device_index = args.camera
    if args.no_serial:
        config.transport.enabled = False

    if config.transport.kind == "serial":
        config.serial.enabled = config.transport.enabled
        config.udp.enabled = False
    elif config.transport.kind == "udp":
        config.udp.enabled = config.transport.enabled
        config.serial.enabled = False


def main() -> int:
    args = _parse_args()
    config = load_config(args.config)
    _apply_runtime_overrides(config, args)
    if args.export_arduino_header:
        export_firmware_headers(config)

    filters = _build_filters(config)
    tracker = HandTracker(config.vision)
    transport_controller = build_transport(config)
    cap = None

    frozen = config.control.freeze_on_start
    estop = False
    status = "startup hold"
    hand_active = False
    tracking_ok = False
    last_valid_time = 0.0
    home_until = 0.0
    startup_pose_until = 0.0
    wave_started_at = 0.0
    wave_until = 0.0
    transport_status = "disabled" if not config.transport.enabled else "disconnected"

    current_base_target_deg = float(config.firmware.base_home_deg)
    current_base_deg = current_base_target_deg
    current_yaw_rate_deg_s = 0.0
    current_gripper_open = config.firmware.startup_gripper_open_fraction
    current_gripper_target_open = config.firmware.startup_gripper_open_fraction
    current_lower_target_deg = 0.0
    current_middle_target_deg = 0.0
    current_upper_target_deg = 0.0
    current_joints = _home_joints()
    current_hand = None
    depth_hold_active = False
    depth_hold_ready = True
    depth_hold_started_at = 0.0
    held_depth_norm = 0.5

    try:
        cap = _open_camera(config)
        transport_controller.connect()
        if not config.transport.enabled:
            transport_status = "disabled"
        elif config.transport.kind == "serial":
            transport_status = f"serial {config.serial.port}"
        else:
            transport_status = f"udp {config.udp.host}:{config.udp.port}"

        if config.control.send_home_on_start:
            home_until = time.perf_counter() + 1.0
            startup_pose_until = home_until + max(0.0, config.control.startup_pose_hold_s)
            if config.control.startup_wave_cycles > 0:
                wave_started_at = startup_pose_until
                wave_until = wave_started_at + (
                    2.0
                    * config.control.startup_wave_half_period_s
                    * config.control.startup_wave_cycles
                )

        previous_time = time.perf_counter()

        while True:
            ok, frame = cap.read()
            if not ok:
                raise RuntimeError("Camera frame grab failed.")

            if config.camera.mirror_view:
                frame = cv2.flip(frame, 1)

            now = time.perf_counter()
            dt = max(1e-3, now - previous_time)
            previous_time = now

            current_hand = tracker.process(frame)
            tracking_ok = current_hand is not None

            if tracking_ok:
                signals = extract_signals(current_hand, config)
                x_norm = filters["x"].update(signals.x_offset_norm)
                height_norm = filters["height"].update(signals.height_norm)
                raw_grip_norm = signals.gripper_open

                if signals.finger_curl_norm <= config.filters.depth_hold_release_curl_threshold:
                    depth_hold_ready = True
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

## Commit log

2026-04-10 Add files via upload
    Most of the structure is credited to SG90 mini robot arm S9 by FrN (Robot Arm for everyone!)
    by Francis128 is licensed under the Creative Commons - Attribution - Non-Commercial license.
    The custom base is designed to replace the native geared base yaw joint for a direct servo driven yaw.
    The project requires three MG90s and two SG90 servos where the MG90s are used for the base yaw, lower pitch and middle pitch joints while the SG90 are used for the upper pitch joint and the gripper end effector.
    PLA and ABS are advised for structural components and gears respectively.
    4mm steel balls are used in the base to make the yaw motion smoother.
    M2 & M2.5 screws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
    [Arm-L_VRmount_mod.stl, Arm-L_hsg2.3mf, Arm-L_hsg2.STL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]
2026-04-10 Create CAD_README.md with project details
    Added detailed information about the CAD project, including components and materials used.
